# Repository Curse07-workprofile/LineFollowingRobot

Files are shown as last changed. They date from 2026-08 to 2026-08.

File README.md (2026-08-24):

# Line-Following Robot - Main PCB

Custom main PCB designed for a university line-following robot project.

I was responsible for the schematic design, component selection, PCB layout, and hardware testing of the main controller board. 
The board integrates an ATmega328P, regulated power, motor switching, analogue line sensors, user input, and ISP programming.

The mechanical platform and control software were developed by other members of the team.

---
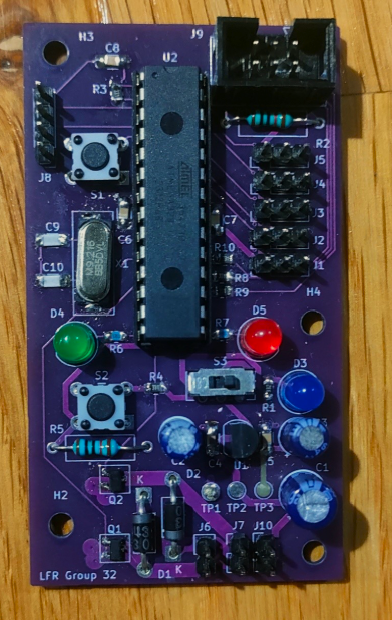
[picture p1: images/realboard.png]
Assembled PCB

---

## Project Overview

The PCB was designed to provide the electrical platform for a small autonomous line-following robot.

### Key requirements

- ATmega328P-based control
- Five analogue reflectance sensors
- Two independently controlled DC motors
- 3.3 V regulated supply
- ISP programming
- User input and status indication
- Reliable operation despite motor-induced supply transients

## My Contribution

I was primarily responsible for the electronics and PCB design:

- Schematic capture and circuit design in KiCad
- Component selection and datasheet research
- Power supply and decoupling design
- Motor driver circuit
- Analogue sensor interface
- ATmega328P peripheral connections
- Crystal oscillator design
- ISP programming interface
- PCB layout and routing
- Hardware assembly and functionality testing
- Component-level debugging and modification

The mechanical chassis and control software were developed by
other members of the team.

## Hardware Architecture

### Microcontroller

**ATmega328P**

The MCU provides:

- ADC inputs for five reflectance sensors
- GPIO for control and status
- SPI for ISP programming
- External 9.216 MHz crystal oscillator

### Power

The board uses a dedicated 3.3 V linear regulator with multiple
levels of decoupling:

- 100 nF local decoupling at MCU supply pins
- 10 µF / 22 µF regulator-side capacitance
- 220 µF bulk capacitance at the battery input

The bulk capacitance was included to reduce supply disturbances
caused by motor current transients.

### Motor Drive

Each motor is controlled using a low-side N-channel MOSFET.

Flyback Schottky diodes provide a current path when the motor
switches off, limiting inductive voltage transients.

### Line Sensors

Five TCRT5000 reflectance sensors provide analogue measurements
through the ATmega328P ADC.

Rather than reducing the sensors to binary black/white states,
the analogue signal was retained to provide the control software
with continuous reflectance information.

## Design Considerations

### Crystal Oscillator

The 9.216 MHz crystal load capacitors were calculated using the
crystal's specified load capacitance and estimated stray
capacitance rather than selecting a standard capacitor value
without calculation.

### ISP Interface

The SPI programming interface includes 330 Ω series resistors on
SCLK, MOSI and MISO.

These were selected to limit transient current while maintaining
appropriate signal levels at the 3.3 V logic voltage.

### PCB Layout

Particular attention was given to separating sensitive analogue
sensor routing from the high-current motor switching paths.

Decoupling capacitors were positioned close to their associated
supply pins, and the ground plane was maintained as continuously
as practical around the sensor circuitry.

## Hardware Bring-Up & Iteration

The first hardware revision provided several useful lessons that
would not have been apparent from schematic or simulation alone.

During bring-up I identified and corrected several issues,
including:

- Status LED initially producing substantially more light than
  intended; the series resistor was recalculated and replaced.
- A power-switch footprint was found to have incorrect pin mapping;
  the physical component was adapted to match the intended circuit.
- Motor supply behaviour highlighted the importance of bulk
  capacitance and supply integrity during high-current transients.

These iterations were useful in demonstrating the difference
between a theoretically correct circuit and a practical PCB
operating in a complete electromechanical system.

## Project Outcome

The PCB itself was successfully assembled and brought up.

However, the complete line-following robot did not achieve the
intended performance. Problems encountered during integration
were primarily associated with the mechanical platform and the
interaction between the electrical and mechanical systems.

This was an important lesson in system-level engineering: a
functional subsystem does not necessarily result in a functional
complete system when mechanical, electrical and software
interfaces are not considered together.

## Skills Demonstrated

- KiCad schematic capture and PCB layout
- ATmega328P embedded hardware
- Mixed analogue/digital PCB design
- Power supply design
- Decoupling and transient management
- MOSFET motor switching
- Flyback protection
- Analogue sensor interfacing
- ADC design
- SPI / ISP programming
- Datasheet-based component selection
- Circuit calculations
- Hardware bring-up and debugging
- PCB fabrication and assembly
- System-level engineering

## Resources

- [KiCad Schematic](./images/full_skem.png)
- [PCB Layout](./images/fullPCB.png)
- [PCB Design Files](./PCB_design/)
- [Board Photos](./board.md)
- [Project Report](./LFR_report.pdf)

---
*Developed as part of a university group project. Main PCB design and electronics by myself (Curtis Christian); other tasks covered in the report are done as collabarative effort by our group.*

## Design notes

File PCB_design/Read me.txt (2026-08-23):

Main PCB design with Gerber Files, If it's all cool I want Purple Board but if not don't worry. Other sensor designed boards included here.  "LFR_PCB_Main" is file directory for the main board and Gerbers, For Sensor and associated Gerbers see sensors for design 1. Then see Sensor2 for alternative design. Other directories are libraries. All boards are preliminarily ready if oked.

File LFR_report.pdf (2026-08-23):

ENMT221 – MECHATRONICS DESIGN

# Line Following Robot Project Document

## Group 32: Callum Crilly, Curtis Christian, Oliver Glossop and Daniel Middleton

## Team Members

Name: | Role: | Signature:
Curtis Christian | Lead Product Designer | Curtis Christian
Oliver Glossop | Programmer | Oliver Glossop
Callum Crilly | Mechanical Technician | Callum Crilly
Daniel Middleton | Electrical Technician | Daniel Middleton

## Abstract

This project used a mixture of electrical, mechanical and software design to construct a mostly functional Line Following Robot featuring specially designed PCBs for sensor and motor control, powered by PID program ran on an ATmega328P-U. The physical design used two independent back wheels featuring a geared transmission from associated motors, and a third omnidirectional marble wheel to allow for smooth turning. However, this project faced continuous hardware problems throughout construction and testing which eventually led to unrecoverable damage to the PCBs and components.
While the final robot never managed to complete a full lap of the test course due to technical issues, the underlying programming and physical systems demonstrating partial functionality. The partial functionality it was able to achieve was applied use of the line sensors, a calibration routine, and proportional and differential control performing reliably during testing. While flawed, the LFR could have been made to function with only a few tweaks if the hardware instability had not caused such major circuit damage.

Despite all the setbacks this project provided valuable lessons in PCB design, embedded system programming and design iteration in a team context. Many lessons were learned which will undoubtably lead to more successful projects in the future.

## Project Overview

The directive for this project was to design and construct a Line Following Robot capable of completing an unknown course as fast as possible, racing against other LFRs. Speed was the only important design criteria for this project; a mixture of Programming, Electronic Design and Mechanical Design was required to make an efficient and powerful LFR that was still reliable. This project was constrained by a six-week deadline and a limited pool of resources, which incentivised a quick and simple solution that could feasibly be built and delivered on time.

## PCB Design

The main-board architecture was designed for robustness, ease of assembly, and straightforward sensor-to-actuator control. An ATmega328P-U through-hole package was selected as the microcontroller because it simplifies soldering and allows simple replacement via a socket if the MCU is damaged. The MCU’s on-chip ADC channels were used to read the line sensors directly, reducing parts count and latency, while two hardware PWM outputs control the motors for reliable speed regulation. This combination yields a compact, serviceable board that supports the robot’s core functions, sensor sampling, control logic, and motor actuation, without unnecessary complexity. see Fig. 8 for full PCB layout and component application.
Power management and brownout prevention were central design themes. A dedicated 3.3 V linear regulator supplies the MCU and sensors to ensure stable logic levels and compatibility with the chosen peripheral components. Local decoupling follows best practice: 100 nF ceramic capacitors near each VCC pin and across the regulator pins to suppress high-frequency noise, complemented by electrolytic bulk capacitors to smooth low-frequency battery ripple. A 220 µF electrolytic placed at the battery connector serves as the primary energy reservoir to reduce supply droop during motor transients; closer to the regulator we used a 22 µF (battery side) and a 10 µF (MCU side) electrolytic to meet the regulator’s stability requirements. A user-accessible power switch was included upstream of the regulator both as a hard power-off and to protect the regulator during programming with external development hardware; a blue LED with a series resistor provides a clear visual indication of the regulator being enabled. These choices prioritise ease of use during real-world operation where motors create large, rapid current demands. See Fig. 1 below for the full voltage regulator schematic.

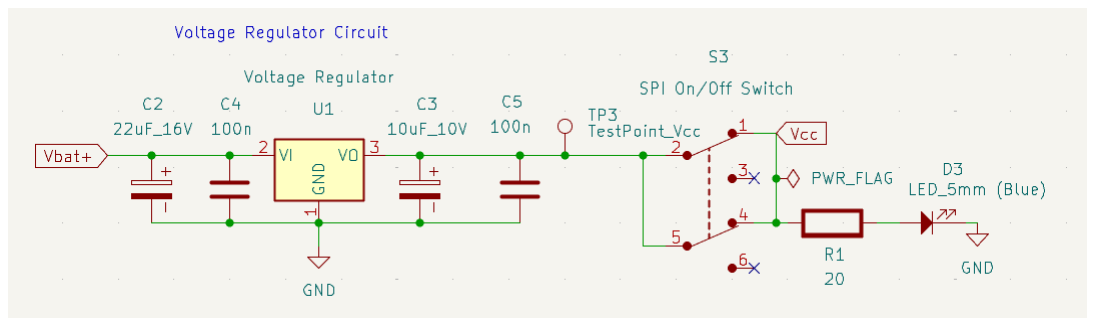
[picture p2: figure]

Fig. 1. Voltage regulator circuit schematic.

Motor drive circuitry was designed for simplicity and protection. Each Multicomp MM28 motor is switched on its low side by N-channel MOSFETs (chosen for low Drain-Source resistance and compact size), with the MOSFET drains tied to the motor negative and sources to the ground plane. The MOSFET gates are driven directly from MCU PWM pins, enabling efficient pulse-width speed control. Schottky diodes are placed across the motor terminals to provide a safe discharge path for inductive energy when switches open; this flyback path prevents inductive voltage spikes from damaging the MOSFETs or the MCU’s I/O. A design decision to keep the battery and motor connectors as simple two-pin headers facilitates mechanical integration and quick replacement during testing. Choice of motor was also obvious, as recommended voltage to run ATmega328P-U was 3.3 V. This meant at least 3 AA NiMH batteries providing 1.2V per cell were needed. This finally meant that given the total pre-regulated voltage would be above 3V and because of this the MM28’s were needed over the MM10’s (they are only recommended to operate at below 3V). See Fig. 2 below, for motor driver circuit schematic.

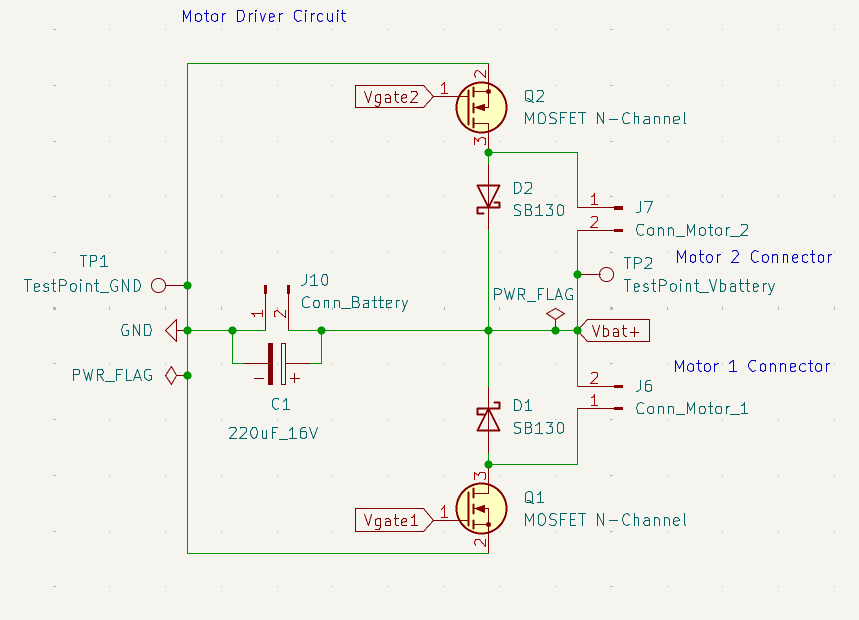
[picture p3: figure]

Fig. 2. Motor driver circuit schematic.

For the clock the values of external capacitance were 30pf calculated from the information in design considerations datasheet. Using the load capacitance of the (9.216 MHz) external crystal oscillator and the stray capacitance (estimated at 5 – 10 pf) gives a range of 26 – 31 pf. 30pf is the most readily available value of ceramic capacitance. See Fig. 3 below for external crystal oscillator schematic.

Fig. 3. External Crystal Oscillator Circuit Schematic

For programming via SPI or Serial Peripheral Interface, there is a six-pin header with recommended resistors between the SCLK, MOSI and MISO inputs there MCU pins. The resistor values are 330 ohms. These are the recommended values used to limit the current on a 3.3V board to 10mA as outlined in the design considerations data sheet. If VCC is connected from this port in programming the switch must be set to off as previously mentioned. see Fig. 4 below for the schematic of the SPI port circuit.

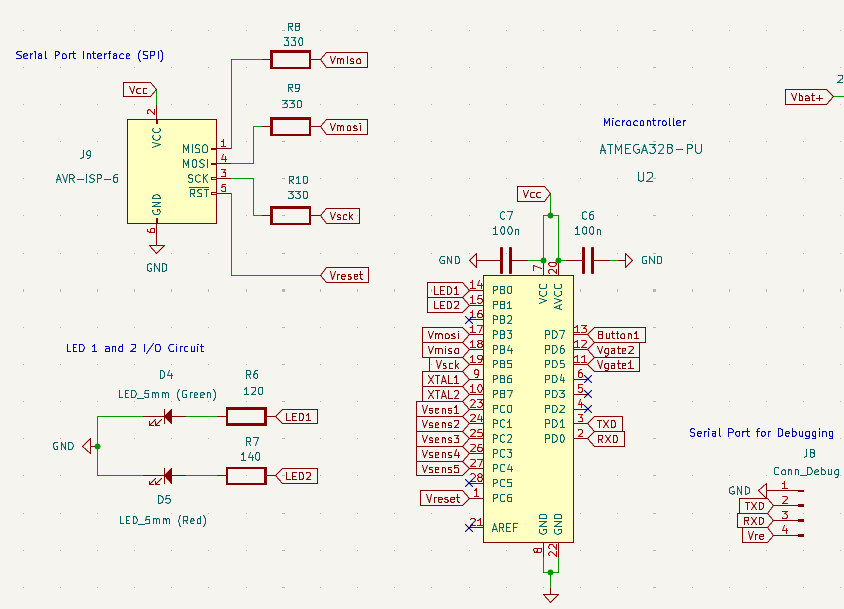
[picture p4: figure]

Fig. 4. Schematic of MCU circuit, serial port, SPI circuit and output LED circuit.

Component-level choices were made to balance performance, availability, and ease of debugging. Two LEDs used for status were sized for ~10 mA nominal forward current; calculated series resistances give predictable, visible illumination without overstressing the 3.3 V regulator or the MCU, see Fig. 4. above for these circuits. Pull-ups and pull-downs use 10 kΩ values to ensure defined logic states without large standby currents; the reset circuit uses a 10 kΩ pull-up with a momentary push button to ground for active-low reset behaviour. Similar to this is the input button used to operate states in software. The button input has the reverse configuration of the reset button, see Fig. 6 for the schematic of the circuit. The DTR–reset 100 nF capacitor allows for a momentary reset pulse instead of holding the MCU in reset for a prolonged period. See Fig. 5 below for the schematic of the full reset circuit.

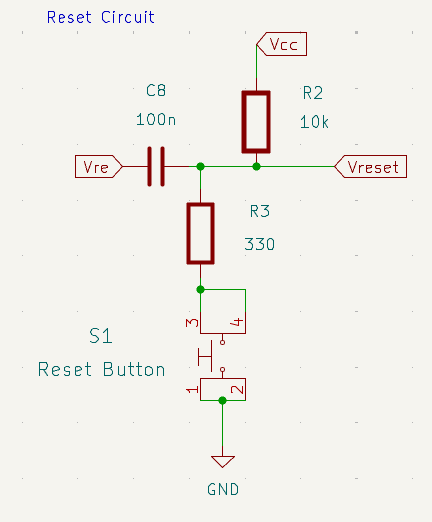
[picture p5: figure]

Fig. 5. Schematic of reset circuit.

Fig. 6. Schematic of the Button input circuit.

The sensor sub-board uses a bottom mounted TCRT5000 reflectance sensors wired for analogue measurement. Each sensor’s collector/emitter output feeds an ADC channel to one of the MCU’s ADC pins (PC0–PC4). Each sensor’s VCC is decoupled with a 100 nF capacitor and uses a modest series resistor on the photodiode LED to limit current; the collector output is pulled toward ground through a 3.3 kΩ resistor to form a stable voltage divider, allowing the ADC to read a continuous reflectance value rather than a binary threshold. See Fig. 7 and Fig. 8 for the TCRT5000 circuit schematic and PCB layout. Locating the five 3-pin headers on the board edge simplifies mechanical mounting and avoids potential component damage. The sensor vias intentionally cut the ground plane to go beneath VCC; these are the only cuts in the ground plane from vias, as good practice. See Fig. 8 to see PCB layout and full circuit combination.

Fig. 7. Circuit schematic of TCRT5000 sensor board.

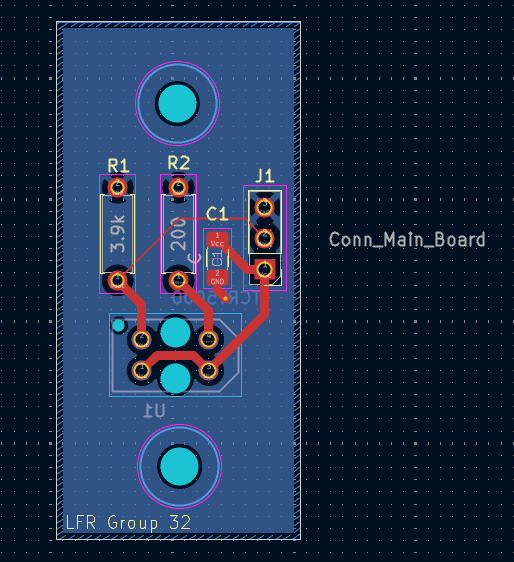
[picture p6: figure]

Fig. 8. PCB layout of sensor boards.

PCB layout choices were driven by noise control serviceability and simplicity. Decoupling capacitors are placed as close as physically possible to the MCU and regulator pins. The large 220 µF bulk capacitor sits adjacent to the battery connector to decouple the largest transients at the entry point. Signal traces for analogue ADC inputs are routed away from high-current motor traces and MOSFET switching nodes to minimize interference. See below for PCB layout of the main board (Fig. 9).

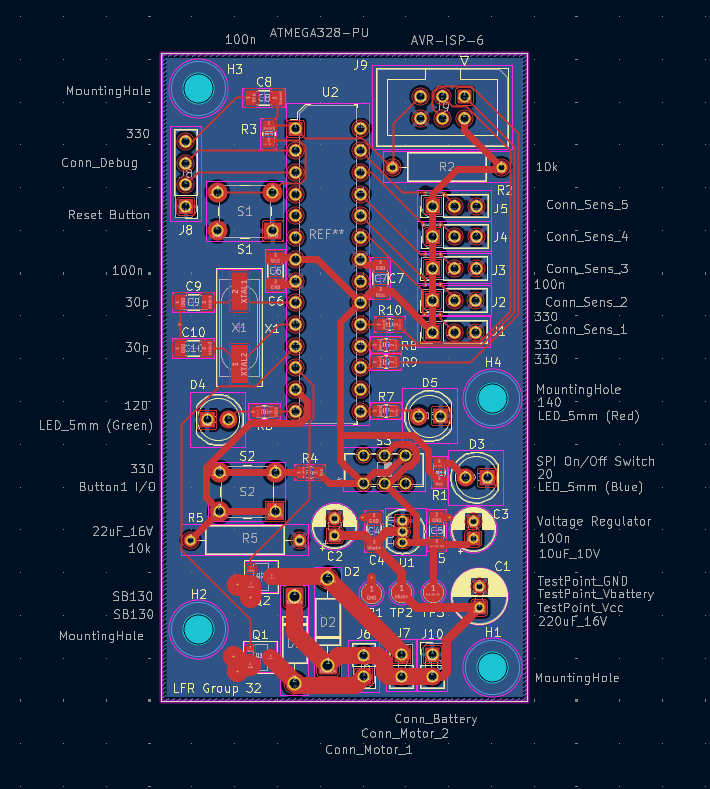
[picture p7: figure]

Fig. 9. PCB layout of main board.

Two minor modifications were implemented during prototyping to improve performance and usability. The blue led was calculated without luminosity intensity in mind where the green and the red were relative in terms luminosity intensity (red ~50mcd and green ~60mcd), the blue LED calculated for a forward current of 10mA (resistance of 20 Ω) had a luminosity intensity of ~300mcd. This was increased to 3.3 kΩ, reducing luminosity to an appropriate level (~10 mcd) for a passive power indicator while extending LED lifespan. Additionally, the power switch (JS202011CQN) had an incorrect pinout relative to the schematic; one leg of the switch was carefully removed to restore correct functionality without compromising the switch operation. This results in the final completed physical main PCB see below, Fig. 10.

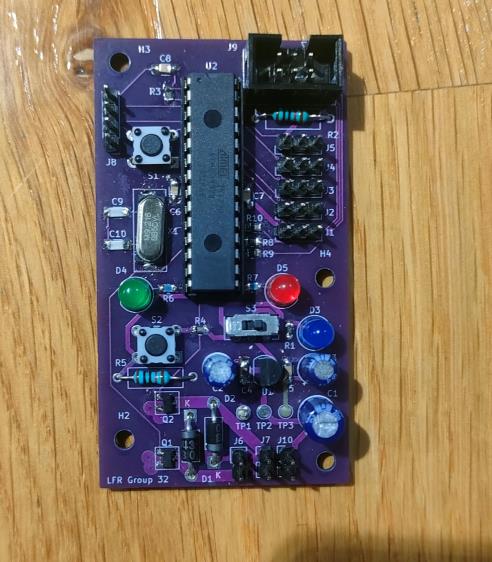
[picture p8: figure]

Fig. 10. Fully soldered main PCB

## Software

The control software for the line-following robot is designed as a three-stage state machine which the user progresses through using a button connected to PD7. Upon powering up, the robot enters an idle state in which no sensors are read, and no motors are driven. This initial state exists purely for safety and allows the robot to remain inactive until the user is ready to begin calibration. See Fig. 11 below for code implementation of the main loop and idle state.

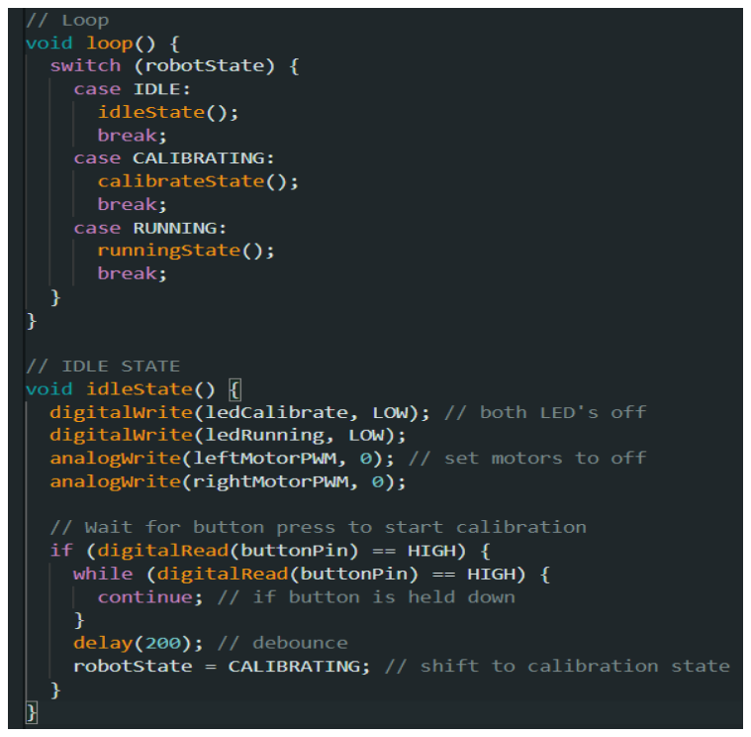
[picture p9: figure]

Fig. 11. Main loop and idle state function.

When the button is pressed, the robot transitions to the calibration phase and turns on the red LED to indicate this mode to the operator. During this phase, the software continuously reads the analogue outputs from the five reflectance sensors, which are connected to the microcontroller’s ADC pins PC0 to PC4. These readings are used to dynamically determine the minimum and maximum values that each sensor can produce under the current environmental lighting and track conditions. As the operator slowly moves the robot horizontally across the track ensuring each sensor passes over both the white background and the black line the software records the lowest and highest values observed for each sensor, with a small margin applied to both to ensure robustness. This adaptive calibration is essential because the sensors’ behaviour can vary noticeably depending on sensor tolerance, temperature, ambient light, and the reflectivity of the track material. See Fig. 12 below for code implementation of the calibration function.

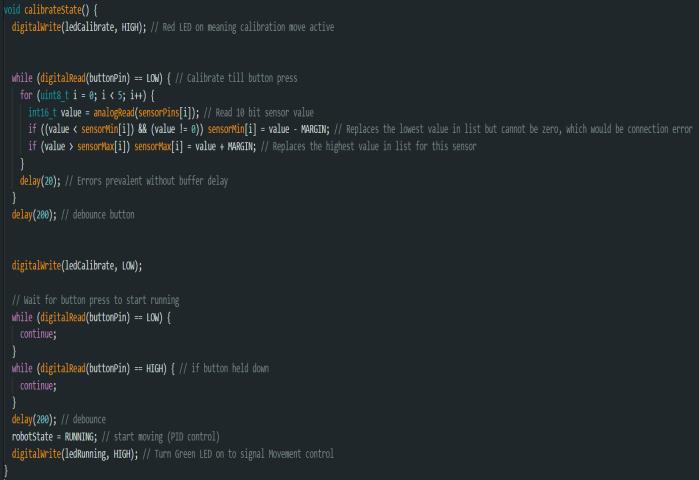
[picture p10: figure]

Fig. 12. Calibration state function.

Once the button is pressed again, the robot briefly returns to idle mode so that it can be safely repositioned at the starting point of the course. The red LED turns off, and on the next button press, the robot enters its active line-following mode and switches on the green LED to confirm that control has begun. At this point the software begins a continuous control loop. Each raw 10-bit sensor reading is immediately mapped into a normalised scale, typically from 0 to 10, where 0 represents white and 10 represents black, using the previously recorded calibration values for that specific sensor. This per-sensor normalisation ensures that all sensors produce consistent and comparable output, even if their raw voltage ranges differ. See Fig. 13 below for code implementation of the read sensor pins function.

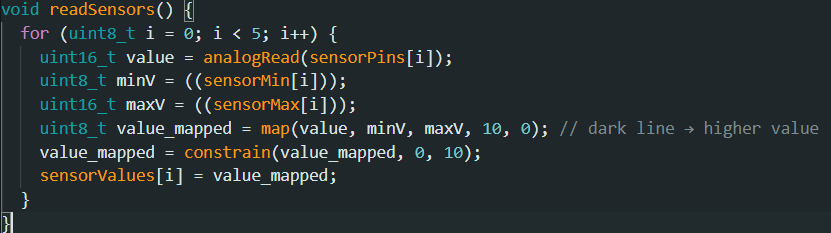
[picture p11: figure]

Fig. 13. Read sensors and reverse map values function.

To determine the position of the line, the software scans the normalised sensor values from left to right and selects the first sensor whose output exceeds a chosen threshold value (for example 7 or higher). This sensor index directly represents the position of the black line relative to the centre of the robot and is immediately converted into an error value, such as −2 when the line is far left, 0 when centred, or +2 when far right. If no sensor currently detects the line, the software retains the last known line position rather than assuming it has disappeared entirely; this prevents erratic behaviour if the line briefly exits the sensor array during a sharp turn. See Fig. 14 below for the code implementation of line position calculation function.

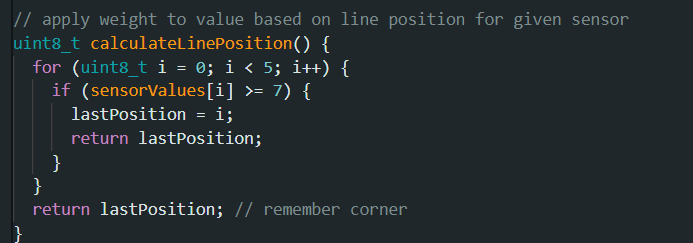
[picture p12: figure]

Fig. 14. Calculate line position function.

This error value is passed into a PID controller, which combines proportional, integral, and derivative terms to compute a correction value. The proportional term responds to the current position error, the integral term accumulates the error over time to eliminate steady-state bias, and the derivative term reacts to rapid changes in error to reduce overshoot. The resulting correction value is then applied to the motor speeds such that it is added to the base speed of one motor and subtracted from the other, causing the robot to steer smoothly back toward the line. Both motor speeds are constrained to remain within a safe range before being written to the motor driver. This control loop repeats continuously until the button is pressed once more, at which point the robot exits back to the idle state. See Fig. 15 below for the code implementation of the running PID control function.

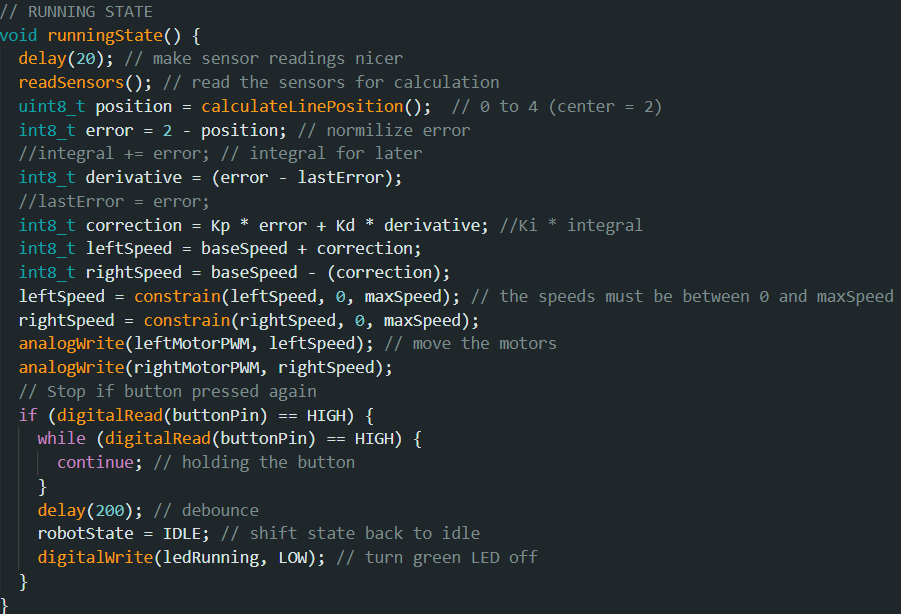
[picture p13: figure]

Fig. 15. Running state function.

## Design Justification

Initially, the control strategy was intended to be more explicitly behaviour based. The goal was to make the robot recognise track features such as corners and respond to them using conditional logic. This approach was attractive as it would be able to deal better with several potential instances perfectly. However, it quickly became clear that implementing reliable corner detection using only reflectance sensors was far more complex than anticipated. Small variations in lighting, floor reflectivity, or sensor tolerance could easily miss the line or misfire completely. In addition, explicitly coding corner handling required extensive manual tuning and created rigid behaviour that did not generalise at all.

This led to a shift toward a continuous feedback approach using a PID wheel-speed controller. Rather than trying to understand the shape of the track, the robot simply corrects its position based on how far it currently is from the line. This method is not only mathematically superior, but also far more generalisable it works equally well for gradual curves and sudden transitions without requiring the robot to ‘know’ the track layout beforehand. Alternative software strategies such as bang-bang (on/off) control were considered but as the PID controlled motor speed was the next increment from the bang-bang, PID was favoured over it. The PID approach offered potential for smoother, self-correcting behaviour, especially when combined with the decision to preserve the last known line position when temporarily lost in software.

On the sensing side, one concept explored was spacing the two outermost sensors further from the centre, aiming to better capture wide-angle bends. However, simulations and physical tests showed that this increased the chance of accidentally detecting off-track reflections or stray lines, especially during repositioning, (in lost mode). The chosen design instead prioritised consistency, using a tightly grouped sensor array and relying on calibration and PID correction rather than physical overspreading. To handle hardware variation and unpredictable environmental conditions, a manual calibration phase was implemented in software dynamically capturing each sensor’s minimum and maximum values under real lighting conditions before line following begins. This eliminated the need to manually hard-code thresholds and significantly improved robustness and adaptability to differing conditions.

In hardware selection, the ATmega328P-U TRT (through-hole) format was deliberately chosen over a surface-mount alternative. Although the SMD version would reduce programming error potentially. The through-hole part made hand-soldering, probing, and part replacement simple, one of the most critical advantages in a beginner prototyping environment. The MCU’s internal ADC was selected over an external ADC module to reduce board and project complexity while still offering sufficient resolution to sense the line position at a given instant.

In summary, both hardware and software design decisions were made through trial and error of potential solutions that were either too difficult, too inflexible or weren’t optimal for the approach that delivered on adaptability and simplicity. The final system is designed intentionally to be simple, tolerant of noise and lighting variation, and designed to be maintainable and educational.

## Mechanical Design

Sensor placement, operating height, and spacing were all good and allowed for optimal readings under the conditions of the track. The spacing of the sensors prevented an absence in line readings when between the two furthermost sensors. The small PCB also allowed for a non-obstructive placement on the body, with an elevated design being chosen as to allow maximum space for the other components. However, the length of the base plate was something that became an overlooked mistake as it created poor weight distribution across the LFR. The original CAD model for the assembled LFR can be seen below in Fig. 16:

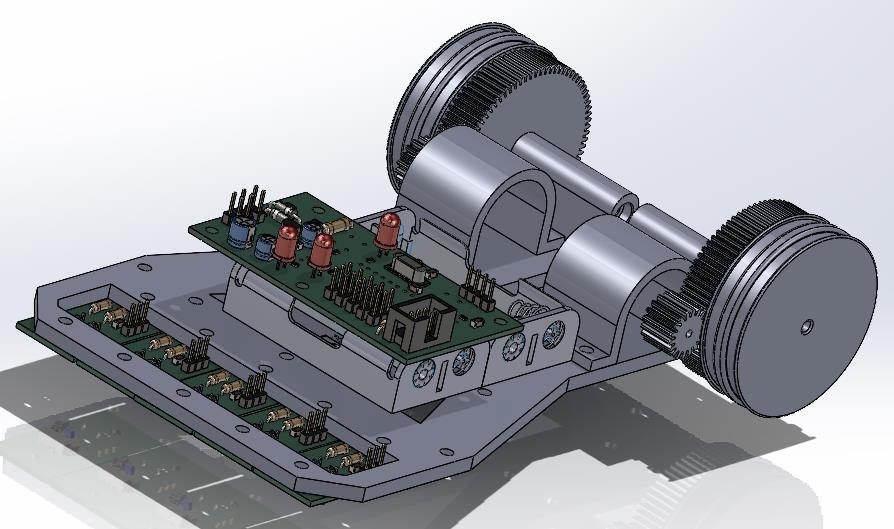
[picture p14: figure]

Fig. 16. CAD Model of LFR Assembly

Placement of weight is incredibly important for robots of this size; there is a lot of weight to move and the motors available are comparatively weak. While the use of gearing ratios (to gear down the motors and increase torque) did help, it was not enough to ensure consistent movement of the robot on the provided track. This will be outlined in further detail later in Iterative Design, but this was a consistent issue during testing caused by problems early in the projects design stage; looking at the original design for the LFR (Fig. 17):

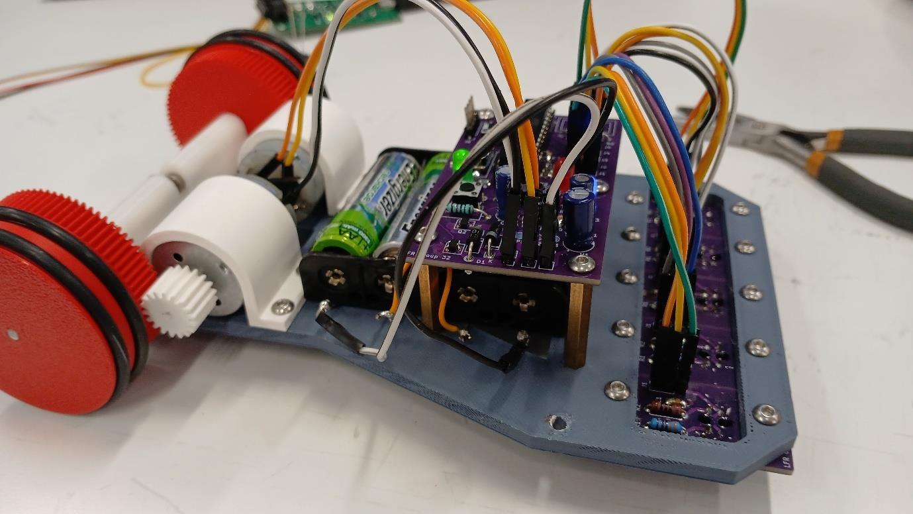
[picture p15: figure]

Fig. 17. Photo of Original Battery Placement

This design had the axle at the back, which works intuitively to maximise turning capabilities and makes balance easy, but leaves most of the weight of the sensors, PCB and batteries to be pushing down on the front of the robot causing increased friction on the front wheel. To solve this, it was decided that the batteries had to be moved back onto the motors and rear axle to relieve most of that force, this new placement can be seen in Fig. 18:

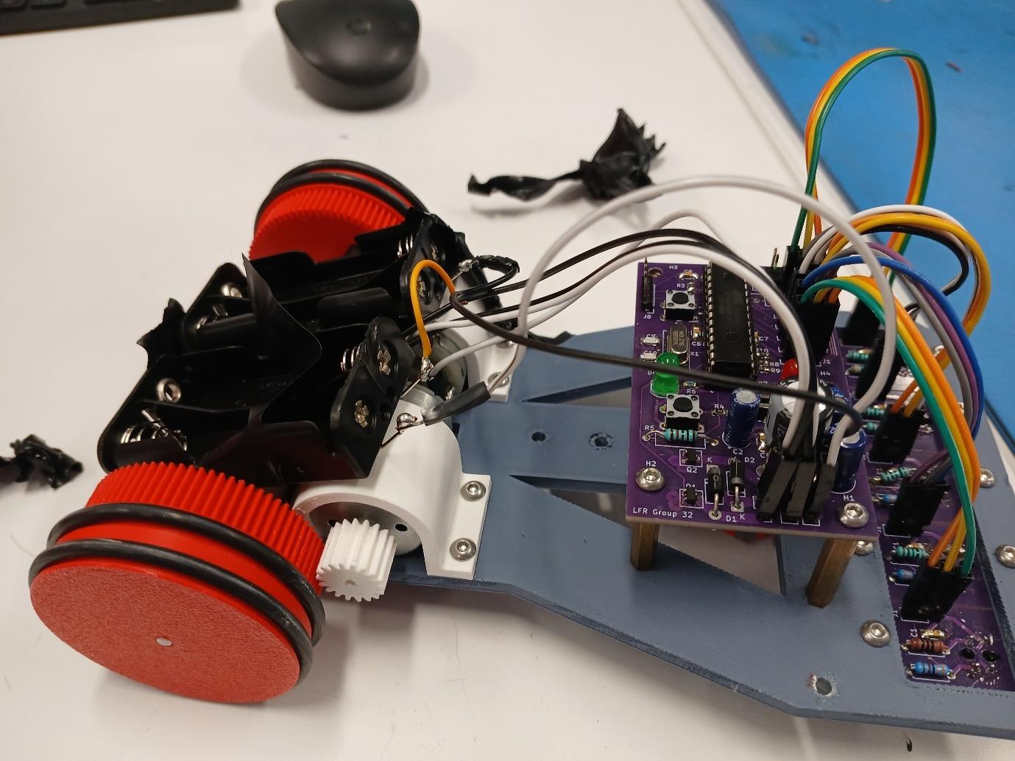
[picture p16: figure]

Fig. 18. Photo of New Battery Placement

Something that could have been greatly beneficial to the final design would have been to expand upon this idea, to further reduce the footprint of the LFR by stacking components vertically as was originally done with the raised PCB.

As touched on before this LFR design implemented a gear connection between the motors and the wheels, this had two main effects: Increasing torque which helped with moving the heavier weights and slowing down the total speed of the LFR. While going slower seems like a negative, due to the high rpm of the Multicomp MM28 motors we were using, the slower speed allowed for greater control of the LFR that would not have been possible without these gears, even with PWM control. Maximising the gear ratio was very important to the overall effectiveness of the design, and the implementation of a more complex 3-gear design could have greatly improved power and control. Unfortunately, as this design only has 2 gears the gear ratio was limited to the size of the wheels and the space in the back of the LFR, which limited the possible power of the design.

## Iterative Design

A clear use of iterative design in the LFR was the front wheel, most online LFRs decide to opt out of using a traditional wheel, instead relying on ‘skid feet’: small smooth feet that provide little resistance and allow the LFR to slide along the ground. Below are the three first trialled feet concepts (Fig. 19):

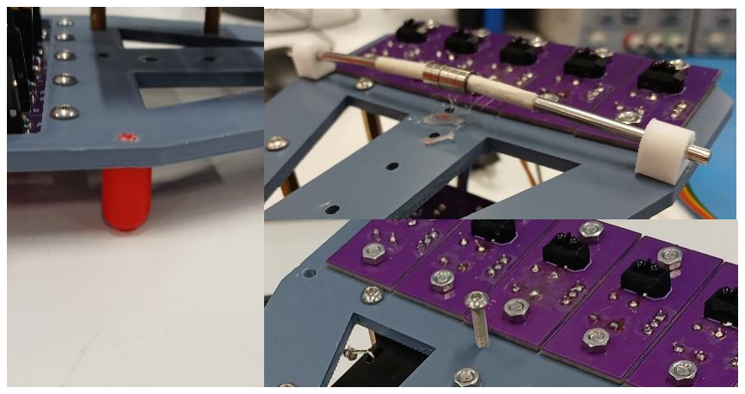
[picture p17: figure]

Fig. 19. Prototype Front Wheel Designs Attempting to copy this design, prototype skid feet were designed and printed, but they created far too much friction both due to the imperfections in the 3D printed material and the distribution of weight in the LFR. An alternative bearing-based wheel was trialled, and while it had far less vertical friction, it had even more horizontal friction which prevented the LFR from turning. Another option that was tried was an extruding bolt, while the smooth metal did slide better than the printed option it was still not enough to get the LFR to move. It was clear a more mechanical solution was needed, and a castor wheel felt like the perfect fit. As seen in Fig. 20 a fully 3D printed ‘shopping trolly’-esque wheel was made, alongside a bearing wheel housing scaled to fit a marble:

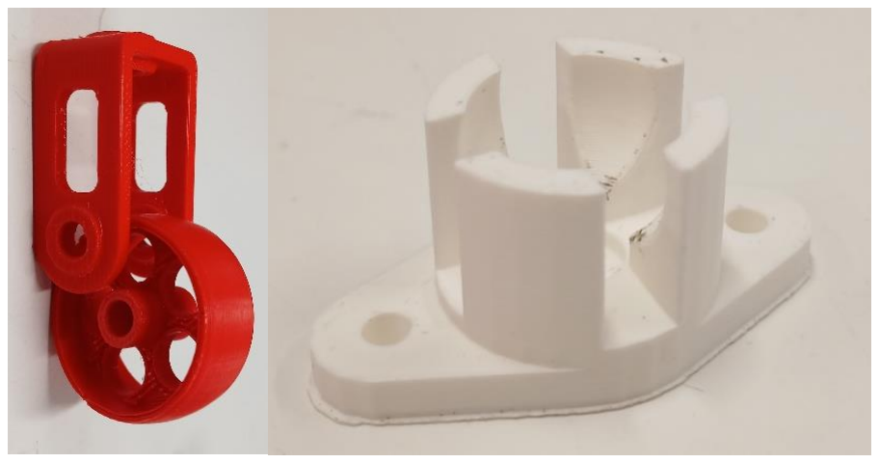
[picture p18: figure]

Fig. 20. Two Front Wheel Test Prints While the shopping trolley wheel was impractical and large, the marble wheel had potential and with some minor modification was able to provide (mostly) frictionless motion in both the vertical and horizontal axes allowing for smooth and controlled motion in the LFR, full implementation of the marble wheel shown in Fig. 21:

Fig. 21. Fully Assembled Marble Wheel

## Final Design

Full Final Design shown in Fig. 22:

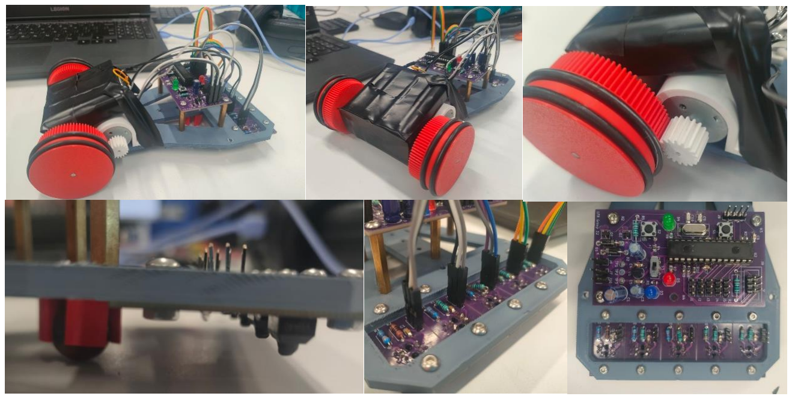
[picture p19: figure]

Fig. 22. Collage of Final Design and Key Features Photos Key mechanical features of the final LFR design were the omnidirectional marble wheel, the geared connection between the motors and the back wheels, and the front bumper. The marble wheel and the geared connection were covered extensively above, but the front bumper was not; this bumper was an extension of the LFR body and both gave a connection point to the second mounting hole of the sensors PCBs (preventing unwanted movement in the sensors) and protected the sensor boards from damage during the several high speed collisions the LFR underwent during testing.

## Results

Unfortunately, during the development of this LFR several serious issues prevented us from being able to ever get the LFR to complete a lap of the test course. The first issue was the poor weight distribution. This prevented the LFR from moving at all unless the motor values were high enough. However, this value would also result in the robot travelling too fast to control. Several coding fixes were attempted, but as discussed earlier in this report the solution ended up being mechanical.

The second issue was far worse and eventually led to the failure of this project. The issue was a mysterious and sudden acceleration of the LFR, which occurred frequently and almost completely at random. Further testing showed these accelerations were not due to any software bugs but were instead physical issues with the circuitry between the board and motors. This issue was seemingly fixed following the implementation of a new 100μF capacitor between ground and VCC, during this relieve we were able to get the LFR fully running and proved that the sensors, PID control and motor speeds were all running as expected. While some PID values still needed to be tweaked the LFR was successfully able to complete the rounded square track. However, as more PID value testing was happening, the LFR suddenly shot off full speed into a wall and then became almost completely unusable. Because of this it appeared the main PCB was damaged as it could no longer driver one motor completely and the other was so weak even at max speed it would not even move, (it just wined). While a backup PCB had been prepared it seemed to have a soldering error about the MOSFET legs as it would not driver the motors at all when plugged in.

The sensors would work fine and could generate a good range of values that were sadly not used fully in this project. However, the graph below (Fig. 23) shows how the sensors were made with the correct spacing. This is because the transition state of each sensor coincides with another with the overlap located below the halfway point of all ranges.

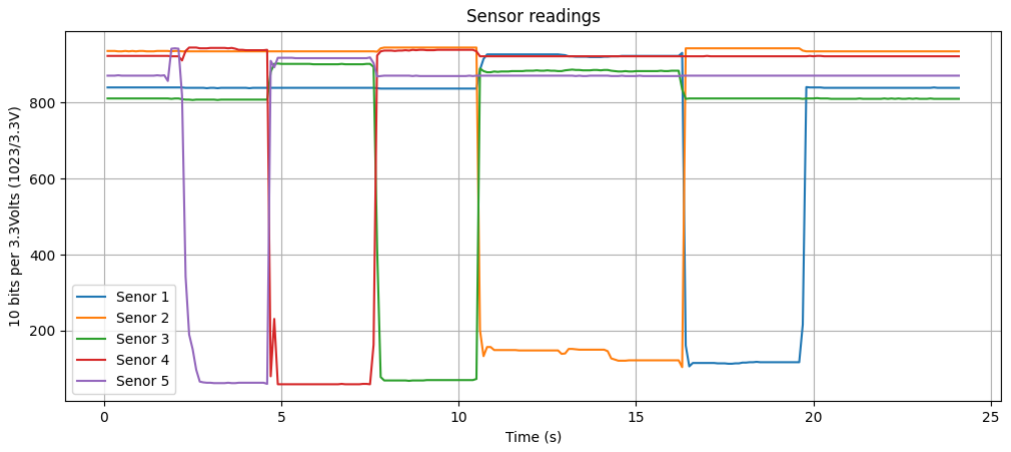
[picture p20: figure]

Fig. 23. Graph of all Sensor Readings over Time

This would mean that further programming and software development could result in a near perfect smoothing and sensor transition curve.

The program that was used in this case produces 0 - 10 output value for each sensor determined by darkness of sensors FOV. Using this to compare the analogue PWM values written to the motor. see this below (Fig. 24).

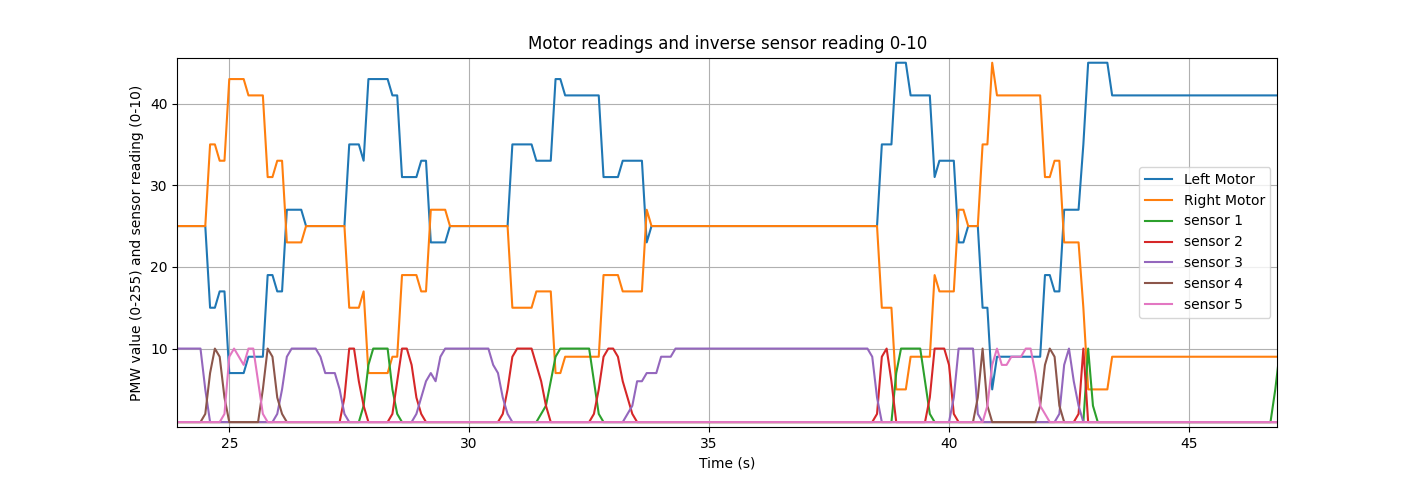
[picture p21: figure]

Fig. 24. Motor and inverse sensor readings

This figure displays a relatively good proportional speed response profile. However, it still does need more tuning time and software improvements to make the most of the analogue sensor values and to produce the desired smooth curve. These improvements were cut short, because of the hardware issues previously mentioned.

## Conclusion

Throughout this project, it was a given requirement to learn about creating a mechatronics solution to a new and constrained problem. Specifically, this project taught a lot about designing PCBs for specific purposes, choosing components for the robot, and troubleshooting issues. Although the LFR didn’t complete the course, it still managed to follow simple square track. Some parts of the project that worked well were the sensor software, which allowed the sensors to give consistent readings and the geared transmission to the wheels which successfully improved torque and lowered the wheel speed without significant slipping and efficiency loss. The major issue of this project (the sudden LFR acceleration) was never fully fixed and eventually fully prevented further testing, but despite this it was still possible to fix what could be fixed and make massive strides towards almost finishing this project. Something that could have been done better would have been to assign tasks better between team members, to clearer define the roles of each team member and better manage team resources.

## Appendices

Appendix A
AI Disclosure Statement:
Generative AI tools such as ChatGPT and Copilot were used in the development of this project. All AI generated material was reviewed for errors. The primary

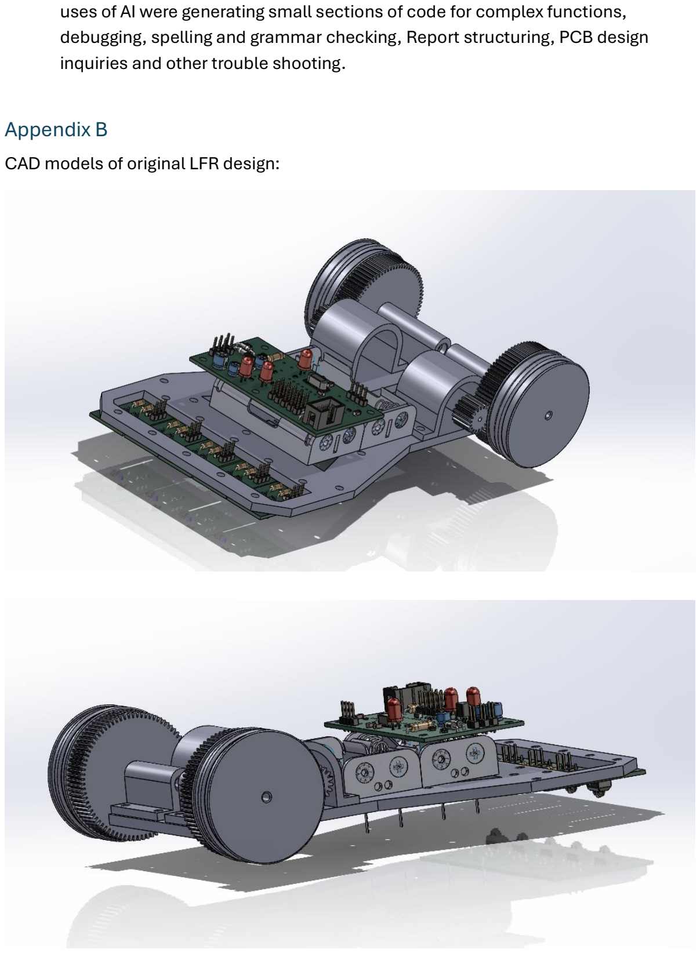
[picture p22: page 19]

uses of AI were generating small sections of code for complex functions, debugging, spelling and grammar checking, Report structuring, PCB design inquiries and other trouble shooting.

Appendix B
CAD models of original LFR design:

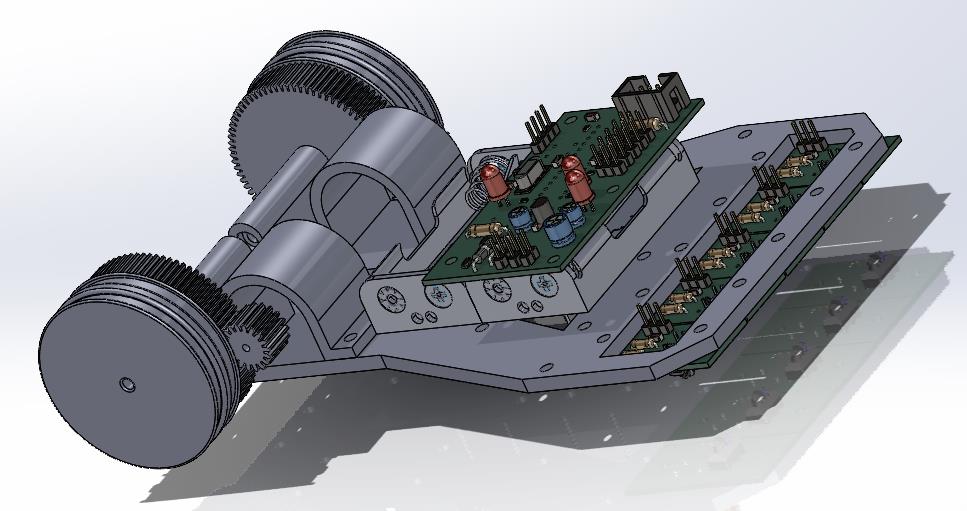
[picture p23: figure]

Appendix C
All code implemented in working LFR:

/ Line Following Robot (PID)

// 5x TCRT5000 sensors (analog inputs) // 2x PWM motor outputs
// 1x Active HIGH button input
// 2x LED outputs for state indication

// Pin Configuration
const uint8_t sensorPins[5] = {A0, A1, A2, A3, A4}; const uint8_t leftMotorPWM = 6;
const uint8_t rightMotorPWM = 5;
const uint8_t buttonPin = 7;
const uint8_t ledCalibrate = 9;
const uint8_t ledRunning = 8;

uint8_t MARGIN = 5; //could be higher for various tracks

// PID Constants
uint8_t Kp = 8;
//uint8_t Ki = 0; // tune later if needed uint8_t Kd = 2;

// Variables
uint8_t sensorValues[5];
uint16_t sensorMin[5];
uint16_t sensorMax[5];

// Globals needed for cross function opperation (some could be refined out of global memory)
int8_t lastError = 0;
uint8_t lastPosition = 2;
uint8_t ticks = 5;
//int16_t integral = 0;
uint16_t time_step = 0;

// Robot speed limits
const uint8_t baseSpeed = 25; // adjust motor strength const uint8_t maxSpeed = 65;

// State management
enum State {
IDLE,
CALIBRATING,
RUNNING
};
State robotState = IDLE;

// Setup
void setup() {
Serial.begin(9600);

pinMode(leftMotorPWM, OUTPUT); pinMode(rightMotorPWM, OUTPUT); pinMode(buttonPin, INPUT); pinMode(ledCalibrate, OUTPUT); pinMode(ledRunning, OUTPUT);

// Initialize sensor calibration ranges for (int i = 0; i < 5; i++) { sensorMin[i] = 1023;
sensorMax[i] = 0;
}

analogWrite(leftMotorPWM, 0); analogWrite(rightMotorPWM, 0); }

// Loop
void loop() {
switch (robotState) {
case IDLE:
idleState();

break;
case CALIBRATING:
calibrateState();
break;
case RUNNING:
runningState();
break;
}
}

// IDLE STATE
void idleState() {
digitalWrite(ledCalibrate, LOW); // both LED's off digitalWrite(ledRunning, LOW); analogWrite(leftMotorPWM, 0); // set motors to off analogWrite(rightMotorPWM, 0);

// Wait for button press to start calibration
if (digitalRead(buttonPin) == HIGH) {
while (digitalRead(buttonPin) == HIGH) { continue; // if button is held down
}
delay(200); // debounce
robotState = CALIBRATING; // shift to calibration state }
}

void calibrateState() {
digitalWrite(ledCalibrate, HIGH); // Red LED on meaning calibration move active
while (digitalRead(buttonPin) == LOW) { // Calibrate till button press for (uint8_t i = 0; i < 5; i++) {
int16_t value = analogRead(sensorPins[i]); // Read 10 bit sensor value if ((value < sensorMin[i]) && (value != 0)) sensorMin[i] = value -MARGIN; // Replaces the lowest value in list but cannot be zero, which would be connection error
if (value > sensorMax[i]) sensorMax[i] = value + MARGIN; // Replaces the highest value in list for this sensor
}
delay(100); // Errors prevalent without buffer delay
}
delay(200); // debounce button digitalWrite(ledCalibrate, LOW);
// Wait for button press to start running while (digitalRead(buttonPin) == LOW) { continue;
}

while (digitalRead(buttonPin) == HIGH) { // if button held down continue;
}
delay(200); // debounce
robotState = RUNNING; // start moving (PID control) digitalWrite(ledRunning, HIGH); // Turn Green LED on to signal Movement control
}

// RUNNING STATE
void runningState() {
delay(100); // make sensor readings nicer
readSensors(); // read the sensors for calculation
uint8_t position = calculateLinePosition(); // 0 to 4 (center = 2) int8_t error = 2 - position; // normilize error
//integral += error; // integral for later
int8_t derivative = (error - lastError);
ticks++;
if (ticks > 5) {
lastError = error;
ticks = 0;
}

int8_t correction = Kp * error + Kd * derivative; //Ki * integral
int8_t leftSpeed = baseSpeed + correction;
int8_t rightSpeed = baseSpeed - (correction);
leftSpeed = constrain(leftSpeed, 0, maxSpeed); // the speeds must be between 0 and maxSpeed
rightSpeed = constrain(rightSpeed, 0, maxSpeed);
// Stop if button pressed
// For display of figures through serial port communications (remove for opperation)
time_step++;
Serial.printf("%d, %d, %d", time_step, leftSpeed, rightSpeed);
for (int i = 0; i < 5; i++) {
Serial.printf(", %d", sensorValues[i]);
}
Serial.println();
Serial.flush();
// drive motors
analogWrite(leftMotorPWM, leftSpeed); analogWrite(rightMotorPWM, rightSpeed);

if (digitalRead(buttonPin) == HIGH) { while (digitalRead(buttonPin) == HIGH) { continue; // holding the button
}

delay(200); // debounce
robotState = IDLE; // shift state back to idle digitalWrite(ledRunning, LOW); // turn green LED off }
}

// Read sensors (normalized 0–10)
void readSensors() {
for (uint8_t i = 0; i < 5; i++) {
uint16_t value = analogRead(sensorPins[i]);
uint8_t minV = ((sensorMin[i]));
uint16_t maxV = ((sensorMax[i]));
uint8_t value_mapped = map(value, minV, maxV, 10, 0); // dark line → higher value
value_mapped = constrain(value_mapped, 0, 10);
sensorValues[i] = value_mapped;
}
}

// apply weight to value based on position uint8_t calculateLinePosition() {
for (uint8_t i = 0; i < 5; i++) {
if (sensorValues[i] >= 7) { lastPosition = i;
return lastPosition;
}
}
return lastPosition; // remember corner }

Appendix D
More figures of plotted data from sensor readings and motor values:

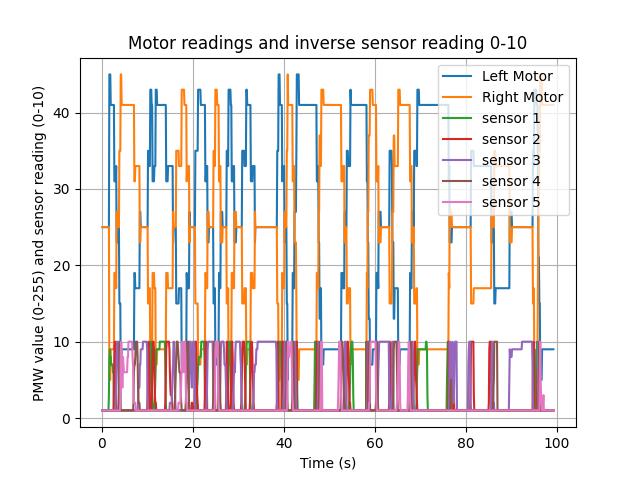
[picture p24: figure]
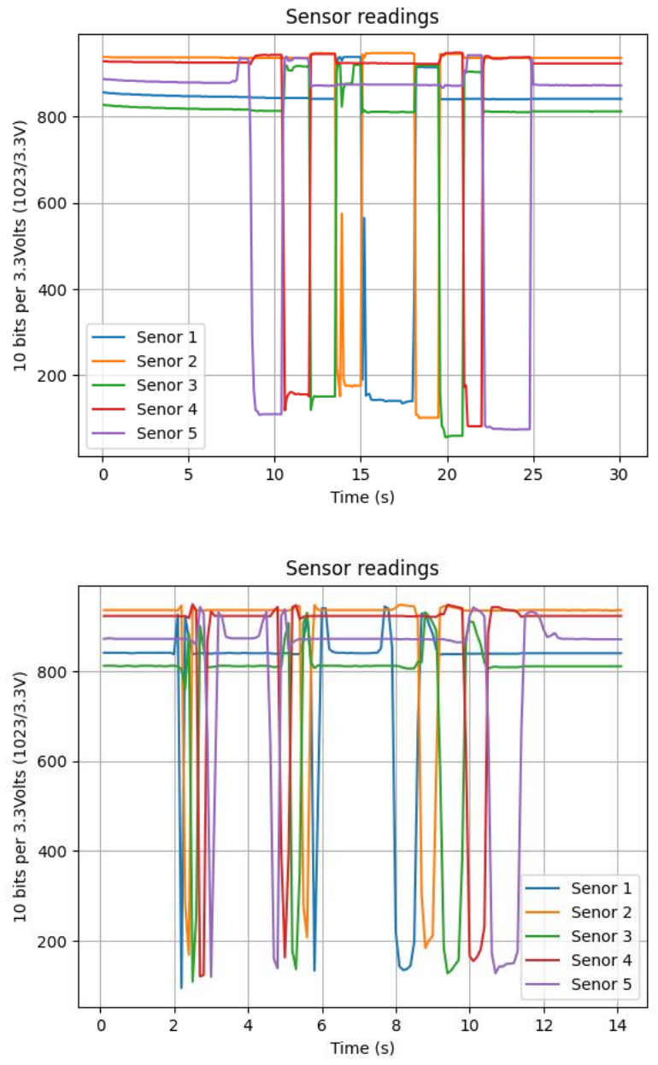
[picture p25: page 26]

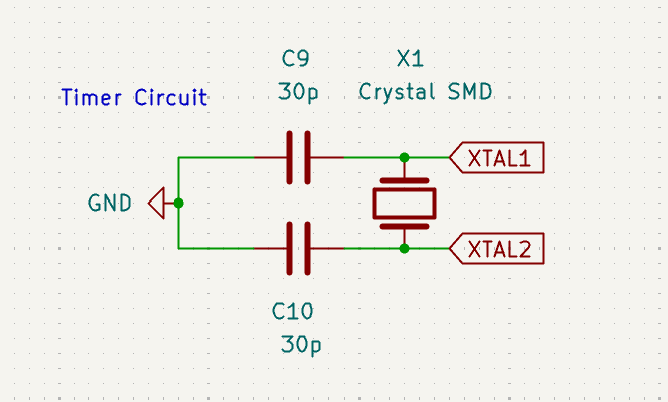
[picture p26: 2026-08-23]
images/clk.png

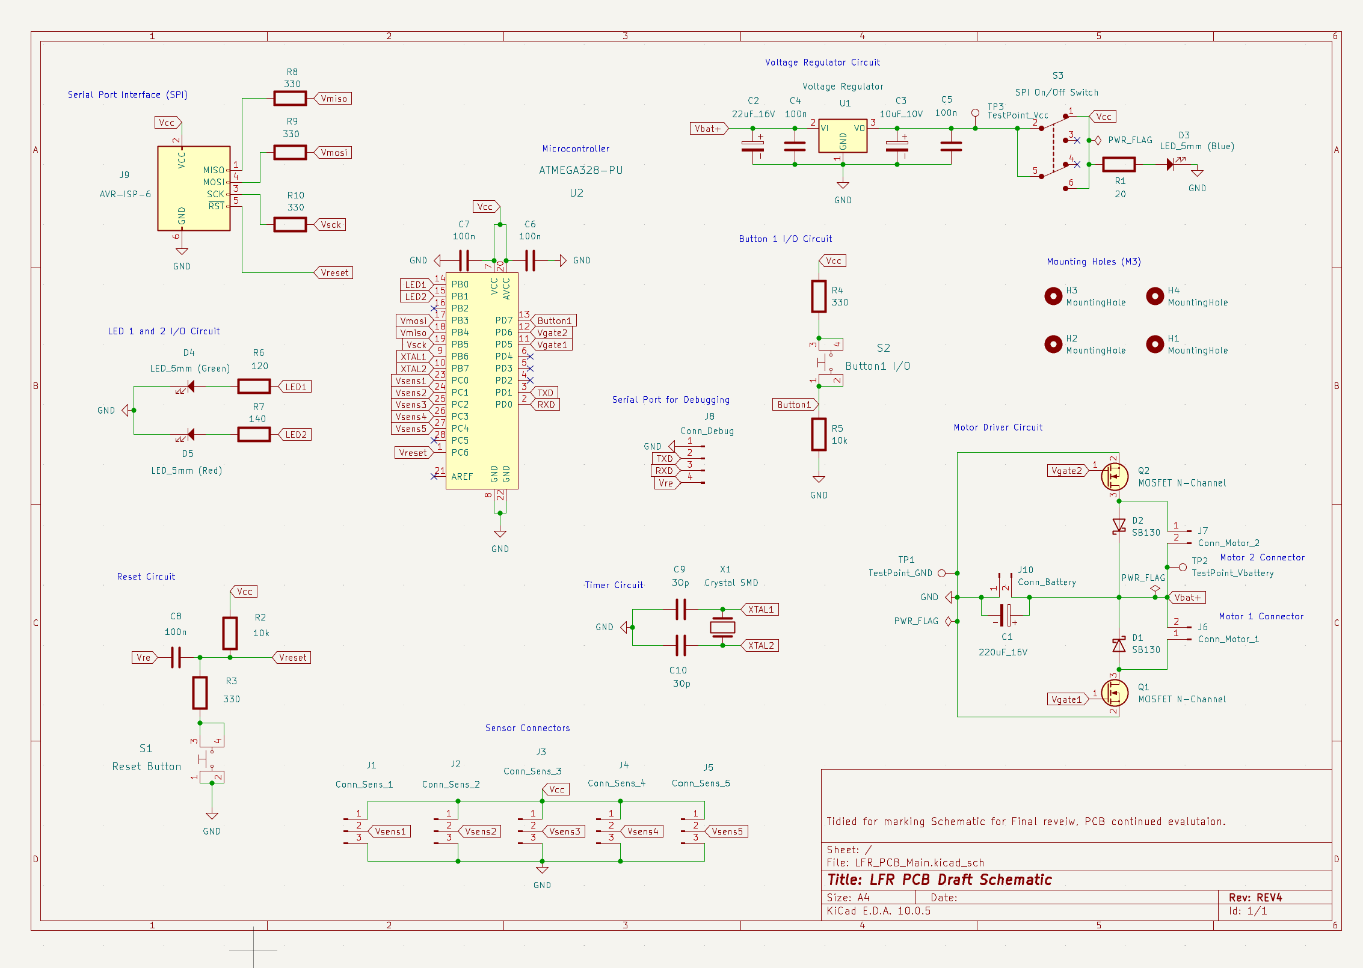
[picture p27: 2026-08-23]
images/full_skem.png

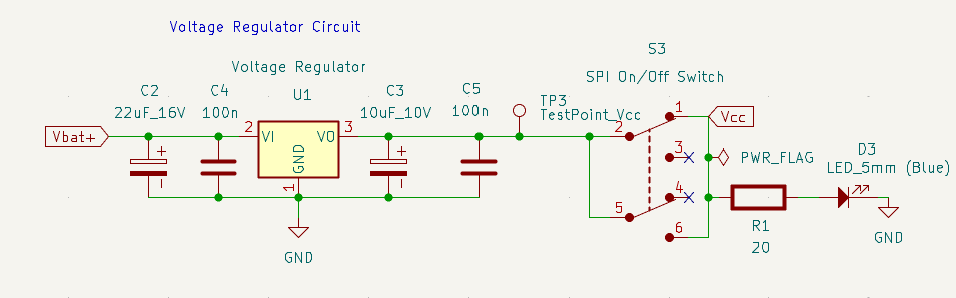
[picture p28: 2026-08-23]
images/voltReg.png

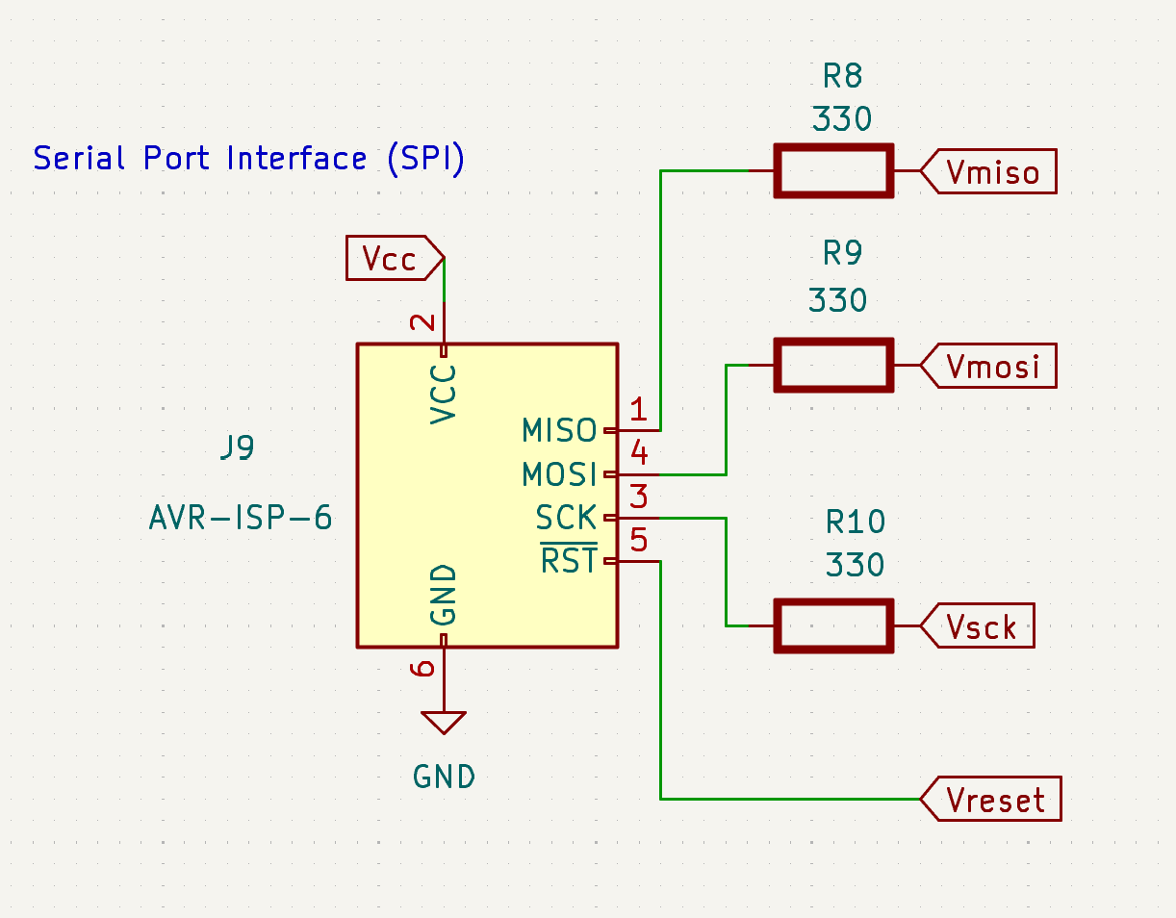
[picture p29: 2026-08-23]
images/SPI.png

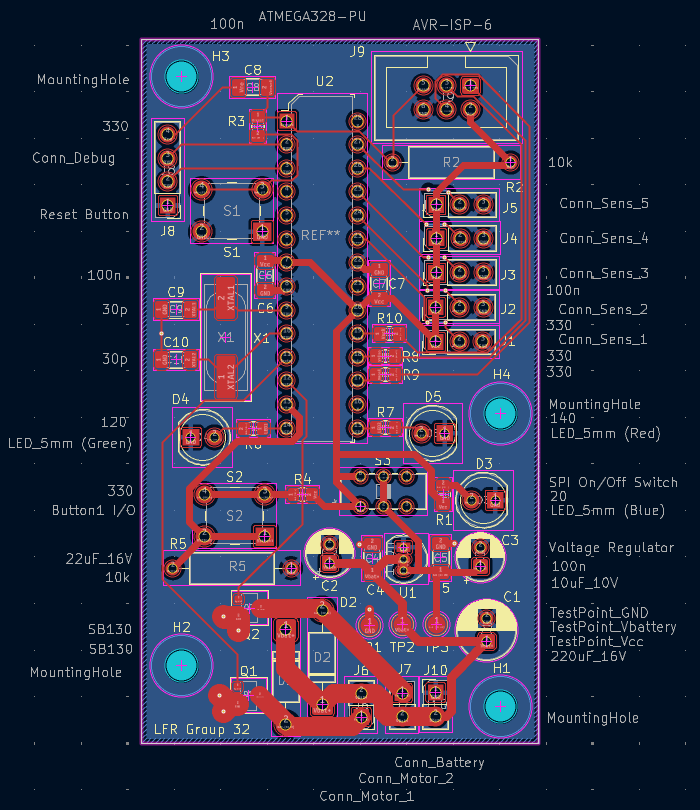
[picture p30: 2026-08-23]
images/fullPCB.png

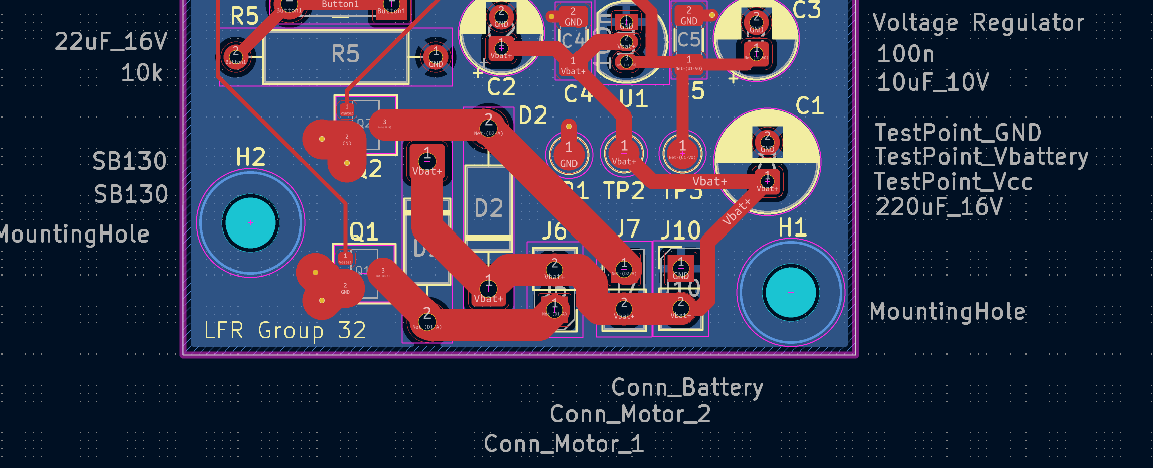
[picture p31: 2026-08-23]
images/lowerPCB.png

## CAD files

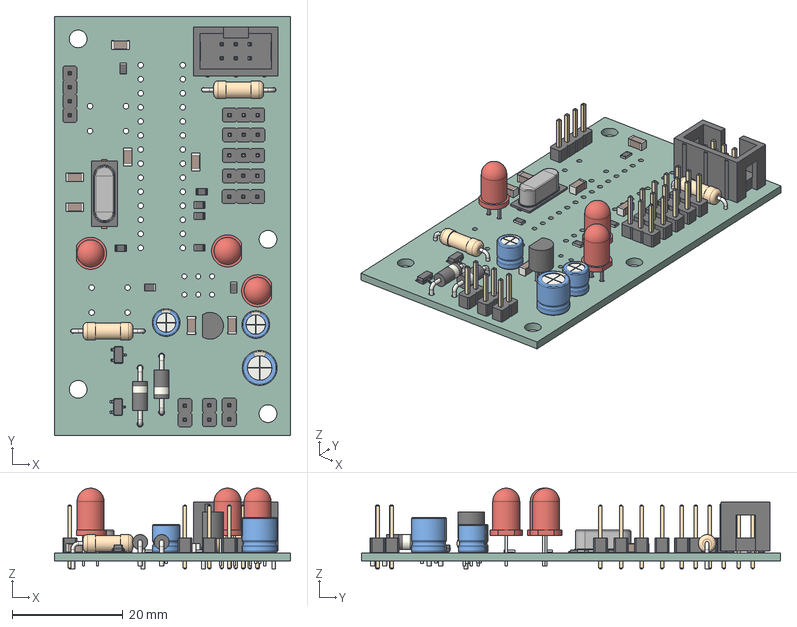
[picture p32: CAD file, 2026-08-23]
PCB_design/LFR_PCB_Main/LFR_PCB_Main.step
42.7 x 75.7 x 14.6 mm
PinHeader_1x04_P2.54mm_Vertical
R_0805_2012Metric x 8
LED_D5.0mm x 3
C_1206_3216Metric x 7
IDC-Header_2x03_P2.54mm_Vertical
Crystal_SMD_HC49-SD
D_DO-41_SOD81_P10.16mm_Horizontal x 2
CP_Radial_D6.3mm_P2.50mm
PinHeader_1x02_P2.54mm_Vertical x 3
SC-59 x 2
PinHeader_1x03_P2.54mm_Vertical x 5
R_Axial_DIN0309_L9.0mm_D3.2mm_P12.70mm_Horizontal x 2
CP_Radial_D5.0mm_P2.00mm x 2
TO-92_Inline
LFR_PCB_Main_PCB

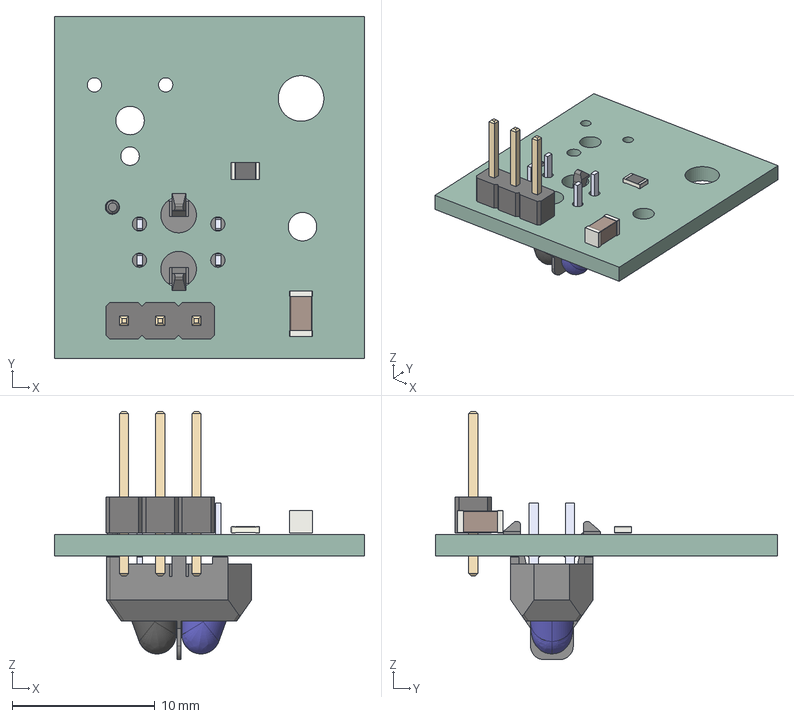
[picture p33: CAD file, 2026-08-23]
PCB_design/Sensor2/Sensor2.step
21.8 x 24.0 x 17.4 mm
PinHeader_1x03_P2.54mm_Vertical
R_0805_2012Metric
C_1206_3216Metric
TCRT5000
Sensor2_PCB

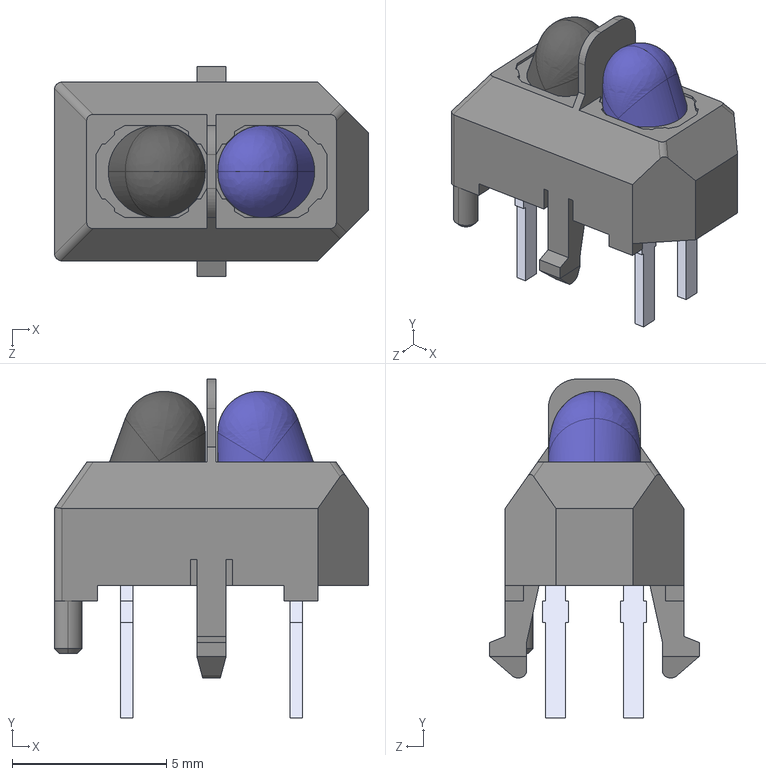
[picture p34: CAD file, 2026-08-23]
PCB_design/Sensor2/TCRT5000/TCRT5000.step
10.2 x 11.0 x 6.80 mm

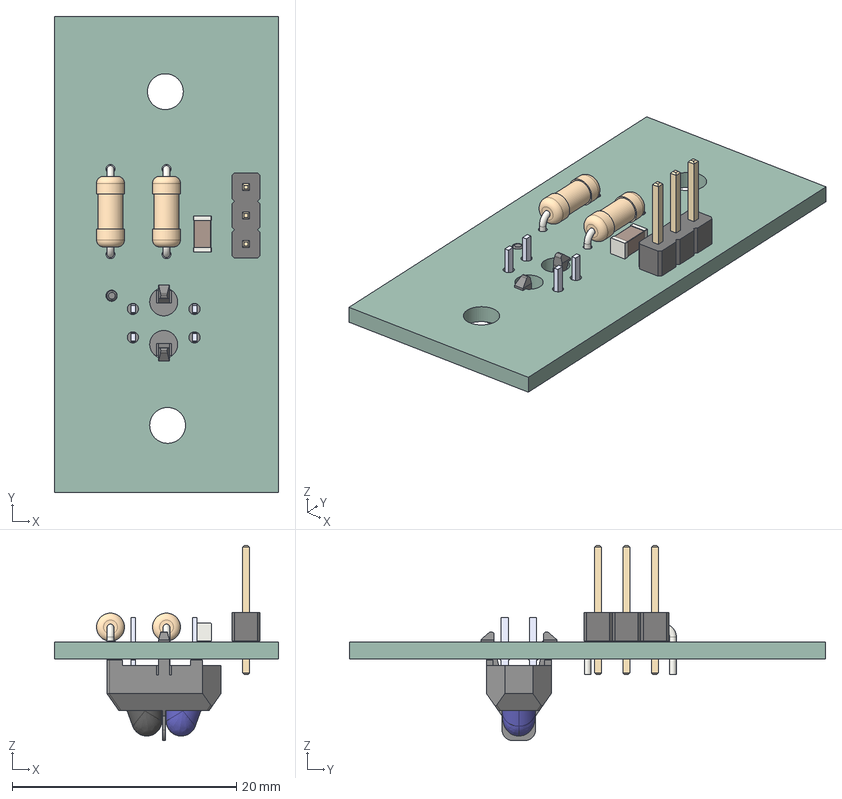
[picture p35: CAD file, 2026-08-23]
PCB_design/sensors/sensors.step
20.0 x 42.5 x 17.4 mm
C_1206_3216Metric
R_Axial_DIN0207_L6.3mm_D2.5mm_P7.62mm_Horizontal x 2
PinHeader_1x03_P2.54mm_Vertical
TCRT5000
sensors_PCB

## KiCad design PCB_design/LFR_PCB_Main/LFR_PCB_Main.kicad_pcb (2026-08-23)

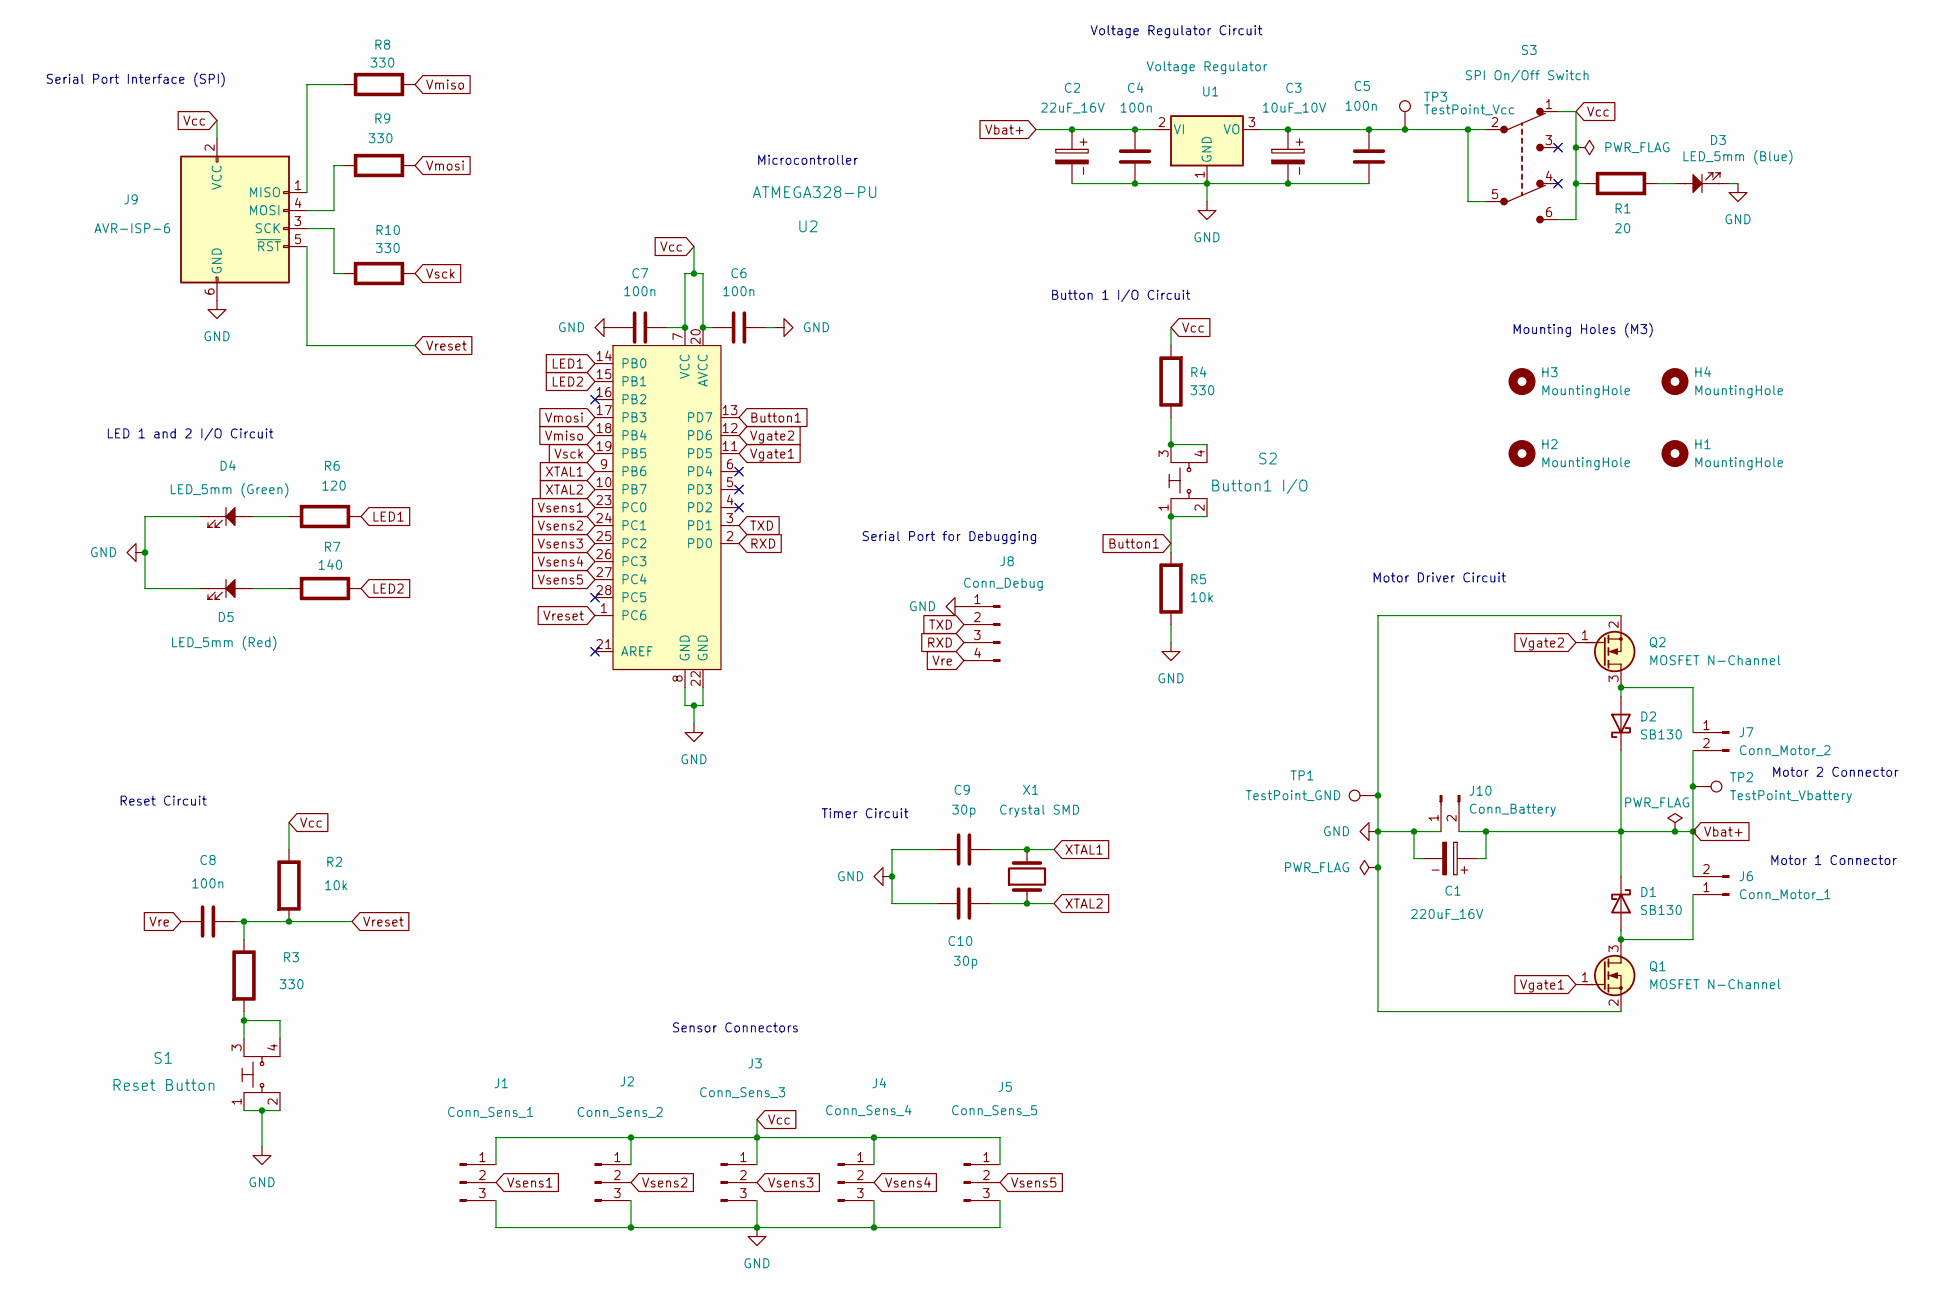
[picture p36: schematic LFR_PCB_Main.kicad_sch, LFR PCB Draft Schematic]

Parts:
C1: 220uF_16V; CP_Radial_D6.3mm_P2.50mm
C2: 22uF_16V; CP_Radial_D5.0mm_P2.00mm
C3: 10uF_10V; CP_Radial_D5.0mm_P2.00mm
C4, C5, C6, C7, C8: 100n; C_1206_3216Metric_Pad1.33x1.80mm_HandSolder
C9, C10: 30p; C_1206_3216Metric_Pad1.33x1.80mm_HandSolder
D1, D2: SB130; D_DO-41_SOD81_P10.16mm_Horizontal
D3: LED_5mm (Blue); LED_D5.0mm
D4: LED_5mm (Green); LED_D5.0mm
D5: LED_5mm (Red); LED_D5.0mm
H1, H2, H3, H4: MountingHole; MountingHole_3.2mm_M3
J1: Conn_Sens_1; PinHeader_1x03_P2.54mm_Vertical
J2: Conn_Sens_2; PinHeader_1x03_P2.54mm_Vertical
J3: Conn_Sens_3; PinHeader_1x03_P2.54mm_Vertical
J4: Conn_Sens_4; PinHeader_1x03_P2.54mm_Vertical
J5: Conn_Sens_5; PinHeader_1x03_P2.54mm_Vertical
J6: Conn_Motor_1; PinHeader_1x02_P2.54mm_Vertical
J7: Conn_Motor_2; PinHeader_1x02_P2.54mm_Vertical
J8: Conn_Debug; PinHeader_1x04_P2.54mm_Vertical
J9: AVR-ISP-6; IDC-Header_2x03_P2.54mm_Vertical
J10: Conn_Battery; PinHeader_1x02_P2.54mm_Vertical
Q1, Q2: MOSFET N-Channel; SC-59
R1: 20; R_0805_2012Metric_Pad1.20x1.40mm_HandSolder; Rating W
R2, R5: 10k; R_Axial_DIN0309_L9.0mm_D3.2mm_P12.70mm_Horizontal; Rating W
R3, R4, R8, R9, R10: 330; R_0805_2012Metric_Pad1.20x1.40mm_HandSolder; Rating W
R6: 120; R_0805_2012Metric_Pad1.20x1.40mm_HandSolder; Rating W
R7: 140; R_0805_2012Metric_Pad1.20x1.40mm_HandSolder; Rating W
S1: Reset Button; Switch_Tactile_THT_6x6mm_MJTP1230; MPN MJTP1230; Digi-Key_PN 679-2428-ND
S2: Button1 I/O; Switch_Tactile_THT_6x6mm_MJTP1230; MPN MJTP1230; Digi-Key_PN 679-2428-ND
S3: SPI On/Off Switch; SWITCH_011CQN; MPN JS202011SCQN; Digi-Key_PN 401-2002-1-ND
TP1: TestPoint_GND; TestPoint_Pad_D2.0mm
TP2: TestPoint_Vbattery; TestPoint_Pad_D2.0mm
TP3: TestPoint_Vcc; TestPoint_Pad_D2.0mm
U1: Voltage Regulator; TO-92_Inline
U2: ATMEGA328-PU; DIP-28_W7.62mm; MPN ATMEGA328-PU; Digi-Key_PN ATMEGA328-PU-ND
X1: Crystal SMD; Crystal_SMD_HC49-SD

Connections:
Button1: R5.2 (-), S2.1, S2.2, U2.13 (PD7)
GND: C1.2, C2.2, C3.2, C4.2, C5.2, C6.2, C7.1, C9.1, C10.1, D3.1, D4.1, D5.1, J1.3, J2.3, J3.3, J4.3, J5.3, J8.1, J9.6 (GND), J10.1, Q1.2 (S), Q2.2 (S), R5.1 (+), S1.1, S1.2, TP1.1, U1.1 (GND), U2.8 (GND), U2.22 (GND)
LED1: R6.1 (+), U2.14 (PB0)
LED2: R7.1 (+), U2.15 (PB1)
unnamed: D1.2 (A), J6.1, Q1.3 (D)
unnamed: D2.2 (A), J7.1, Q2.3 (D)
unnamed: J9.1 (MISO), R8.2 (-)
unnamed: J9.4 (MOSI), R9.2 (-)
unnamed: J9.3 (SCK), R10.2 (-)
unnamed: D3.2, R1.2 (-)
unnamed: R3.2 (-), S1.3, S1.4
unnamed: R4.1 (+), S2.3, S2.4
unnamed: D4.2, R6.2 (-)
unnamed: D5.2, R7.2 (-)
unnamed: C3.1, C5.1, S3.2, S3.5, TP3.1, U1.3 (VO)
RXD: J8.3, U2.2 (PD0)
TXD: J8.2, U2.3 (PD1)
Vbat+: C1.1, C2.1, C4.1, D1.1 (K), D2.1 (K), J6.2, J7.2, J10.2, TP2.1, U1.2 (VI)
Vcc: C6.1, C7.2, J1.1, J2.1, J3.1, J4.1, J5.1, J9.2 (VCC), R1.1 (+), R2.1 (+), R4.2 (-), S3.1, S3.6, U2.7 (VCC), U2.20 (AVCC)
Vgate1: Q1.1 (G), U2.11 (PD5)
Vgate2: Q2.1 (G), U2.12 (PD6)
Vmiso: R8.1 (+), U2.18 (PB4)
Vmosi: R9.1 (+), U2.17 (PB3)
Vre: C8.1, J8.4
Vreset: C8.2, J9.5 (~RST), R2.2 (-), R3.1 (+), U2.1 (PC6)
Vsck: R10.1 (+), U2.19 (PB5)
Vsens1: J1.2, U2.23 (PC0)
Vsens2: J2.2, U2.24 (PC1)
Vsens3: J3.2, U2.25 (PC2)
Vsens4: J4.2, U2.26 (PC3)
Vsens5: J5.2, U2.27 (PC4)
XTAL1: C9.2, U2.9 (PB6), X1.2
XTAL2: C10.2, U2.10 (PB7), X1.1

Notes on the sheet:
Motor Driver Circuit
Reset Circuit
Timer Circuit
Sensor Connectors
Button 1 I/O Circuit
LED 1 and 2 I/O Circuit
Voltage Regulator Circuit
Mounting Holes (M3)
Microcontroller
Serial Port Interface (SPI)
Motor 2 Connector
Motor 1 Connector
Serial Port for Debugging

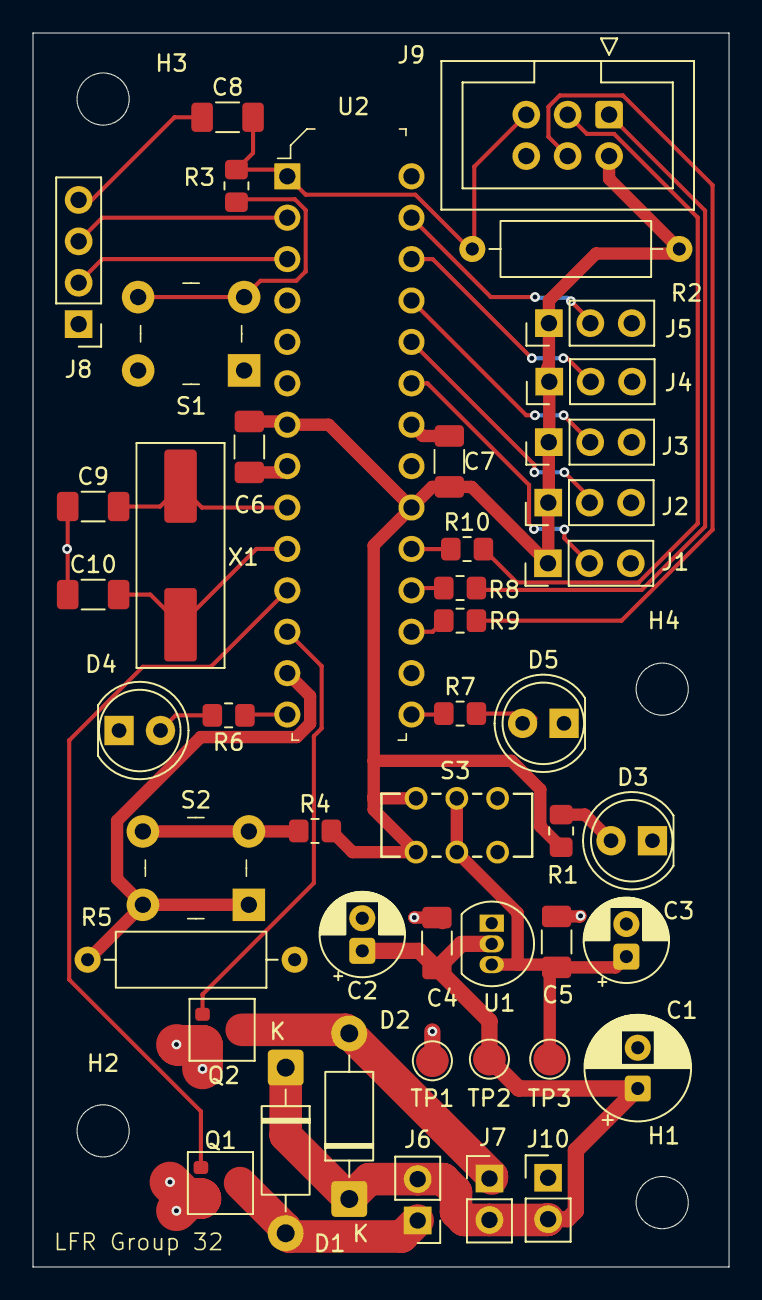
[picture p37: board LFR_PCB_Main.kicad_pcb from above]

Board: 2 copper layers, 42.7 x 75.7 mm, 50 parts (0 on the bottom side), 33 nets.

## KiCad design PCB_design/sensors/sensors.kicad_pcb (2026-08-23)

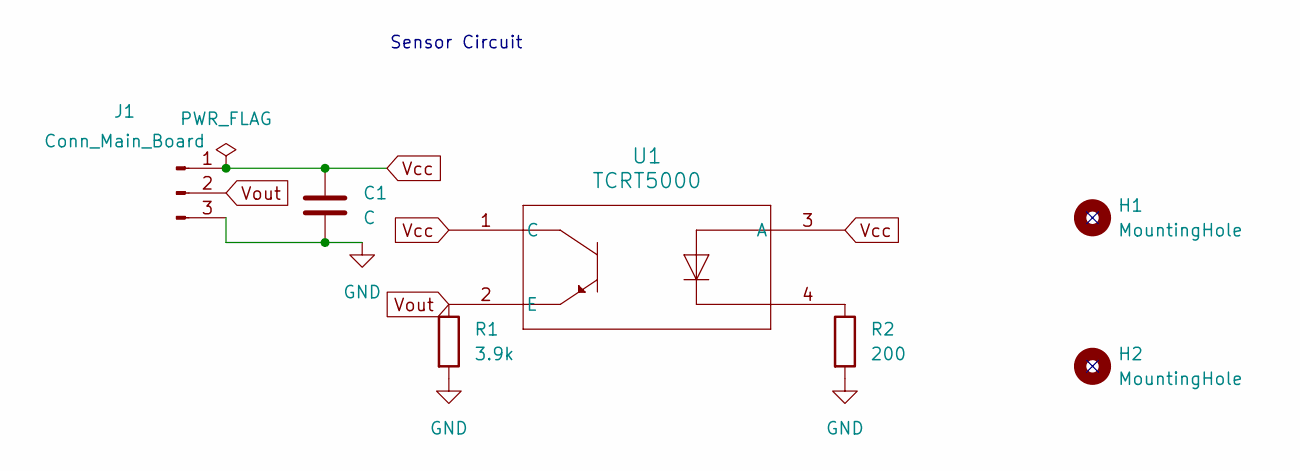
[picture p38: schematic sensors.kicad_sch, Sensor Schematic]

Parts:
C1: C; C_1206_3216Metric_Pad1.33x1.80mm_HandSolder
H1, H2: MountingHole; MountingHole_3.2mm_M3
J1: Conn_Main_Board; PinHeader_1x03_P2.54mm_Vertical
R1: 3.9k; R_Axial_DIN0207_L6.3mm_D2.5mm_P7.62mm_Horizontal
R2: 200; R_Axial_DIN0207_L6.3mm_D2.5mm_P7.62mm_Horizontal
U1: TCRT5000; OPTO_TCRT5000

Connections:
GND: C1.2, J1.3, R1.2, R2.2
unnamed: R2.1, U1.4
Vcc: C1.1, J1.1, U1.1 (C), U1.3 (A)
Vout: J1.2, R1.1, U1.2 (E)

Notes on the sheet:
Sensor Circuit

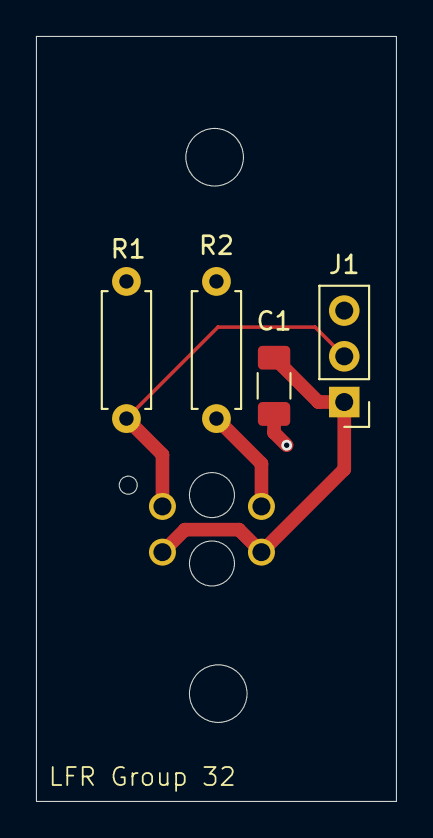
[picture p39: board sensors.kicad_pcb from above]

Board: 2 copper layers, 20.0 x 42.5 mm, 7 parts (1 on the bottom side), 4 nets.

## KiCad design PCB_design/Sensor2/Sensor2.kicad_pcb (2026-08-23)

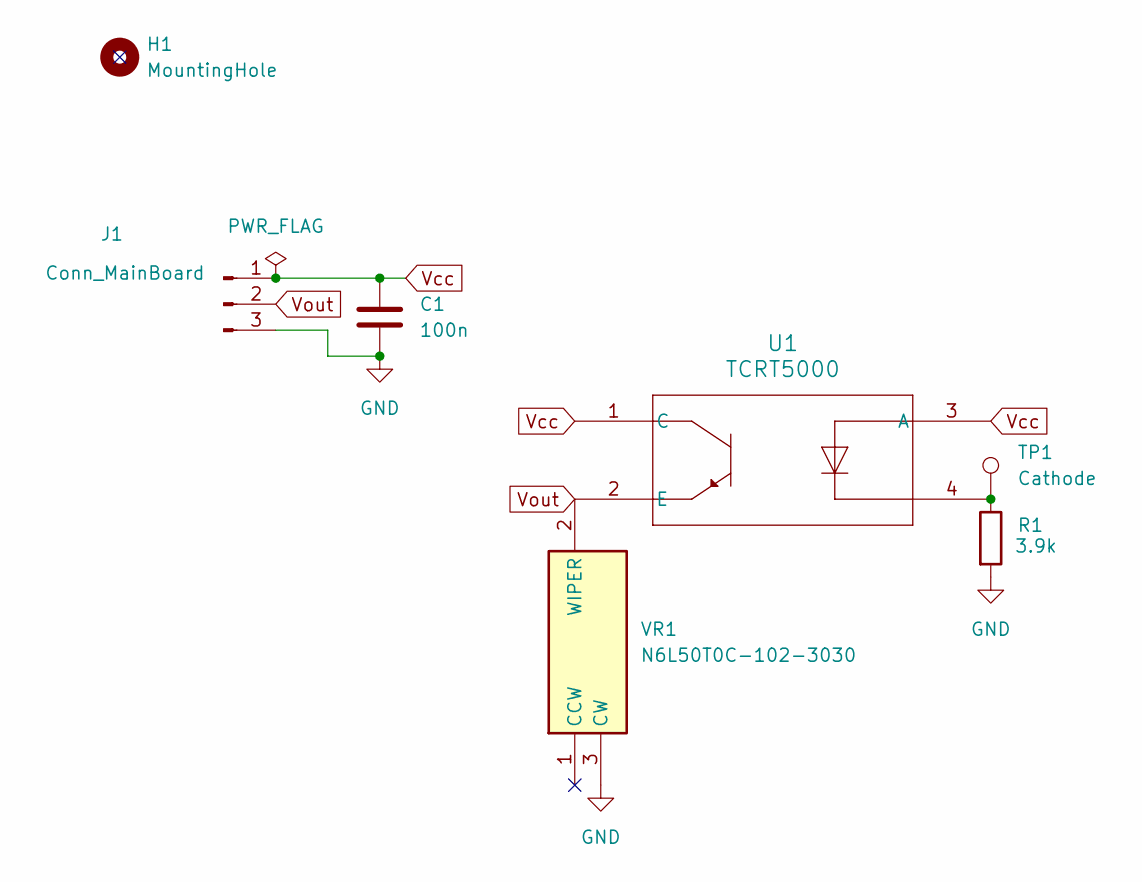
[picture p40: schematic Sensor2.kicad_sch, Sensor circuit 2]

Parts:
C1: 100n; C_1206_3216Metric_Pad1.33x1.80mm_HandSolder
H1: MountingHole; MountingHole_3.2mm_M3
J1: Conn_MainBoard; PinHeader_1x03_P2.54mm_Vertical
R1: 3.9k; R_0805_2012Metric_Pad1.20x1.40mm_HandSolder
TP1: Cathode; TestPoint_Plated_Hole_D2.0mm
U1: TCRT5000; OPTO_TCRT5000
VR1: N6L50T0C-102-3030; N6L50T0C1033030; Mouser Part Number 531-N6L50T0C103-3030

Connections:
GND: C1.2, J1.3, R1.2, VR1.3 (CW)
unnamed: R1.1, TP1.1, U1.4
Vcc: C1.1, J1.1, U1.1 (C), U1.3 (A)
Vout: J1.2, U1.2 (E), VR1.2 (WIPER)

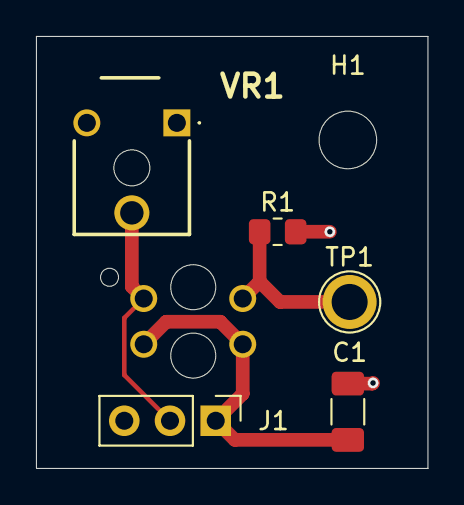
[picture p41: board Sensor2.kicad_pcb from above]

Board: 2 copper layers, 21.8 x 24.0 mm, 7 parts (1 on the bottom side), 4 nets.

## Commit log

2025-09-22 PCB design
2026-08-23 Pictures and report added for context
    [LFR_PCB_Main-B_Cu.gbr, LFR_PCB_Main-B_Mask.gbr, LFR_PCB_Main-B_Silkscreen.gbr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]
2026-08-23 Added Real PCB without comp
